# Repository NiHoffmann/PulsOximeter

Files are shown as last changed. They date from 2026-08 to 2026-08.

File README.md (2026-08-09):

# PulsOximeter

> **Group course project.** This was developed as part of a university course together with a project partner. I was responsible for the majority of the **hardware design**, and did **100% of the firmware and filter/signal processing**. My project partner contributed smaller parts of the hardware design (given that he was new to hardware design) and developed the **Android app**.

## Overview
This project implements a complete pulse oximeter system, combining:
- Custom hardware design  
- Embedded firmware development  
- Signal processing (filtering and peak detection)  
- A simple Android app connected via Bluetooth Low Energy (BLE)  

The system measures pulse and oxygen saturation and displays the results in real time on a mobile device.

---

## Hardware
Custom-designed and built PCB with integrated pulse/oximeter sensor.

<p align="center">
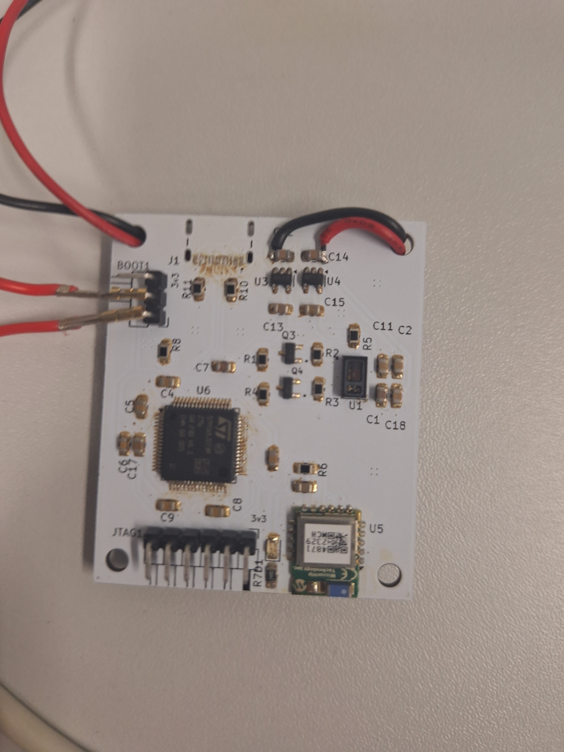
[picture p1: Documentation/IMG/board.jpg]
Hardware Build
  
</p>

---

## Signal Processing
The main emphasis of this project is robust pulse detection from noisy sensor data.
- Bandpass filter designed for 0.8 – 3.5 Hz  
- Covers typical human heart rate range (1.0 – 3.3 Hz) with margin  
- Reduces noise and motion artifacts  
- Enables reliable peak detection for pulse extraction  

Filtered and processed signal:

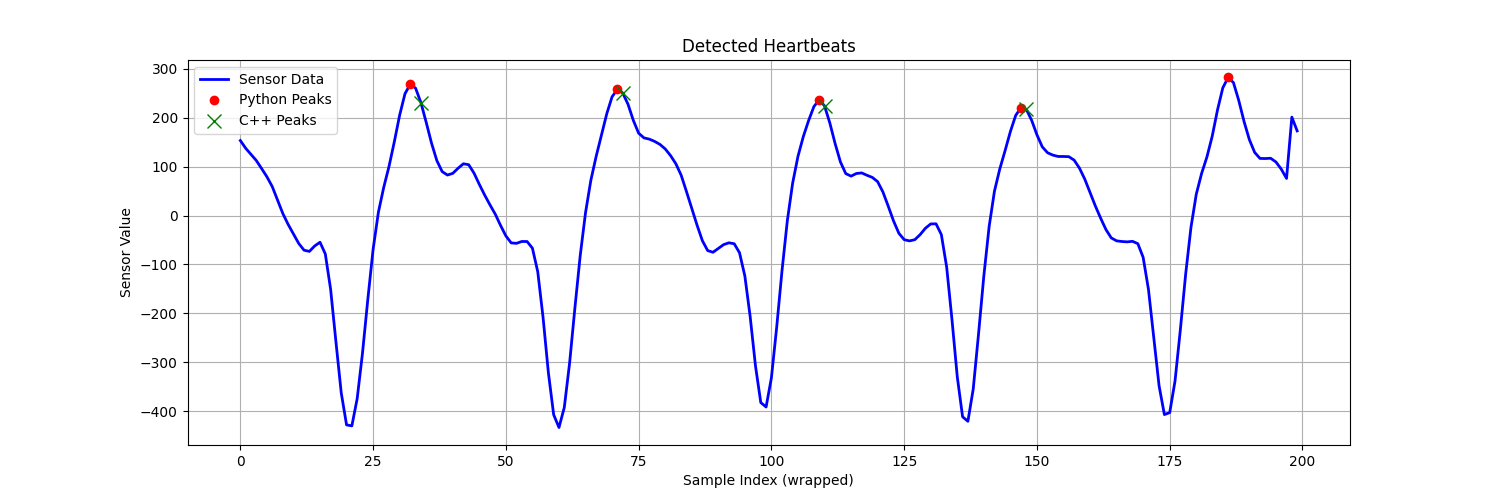
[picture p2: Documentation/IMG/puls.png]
Processed Pulse Signal


> **Filter robustness:** the bandpass filter reliably extracts the pulse waveform whether the raw sensor input is already clean or heavily corrupted by noise.
>
> | Clean Input | High-Noise Input |
> |:---:|:---:|
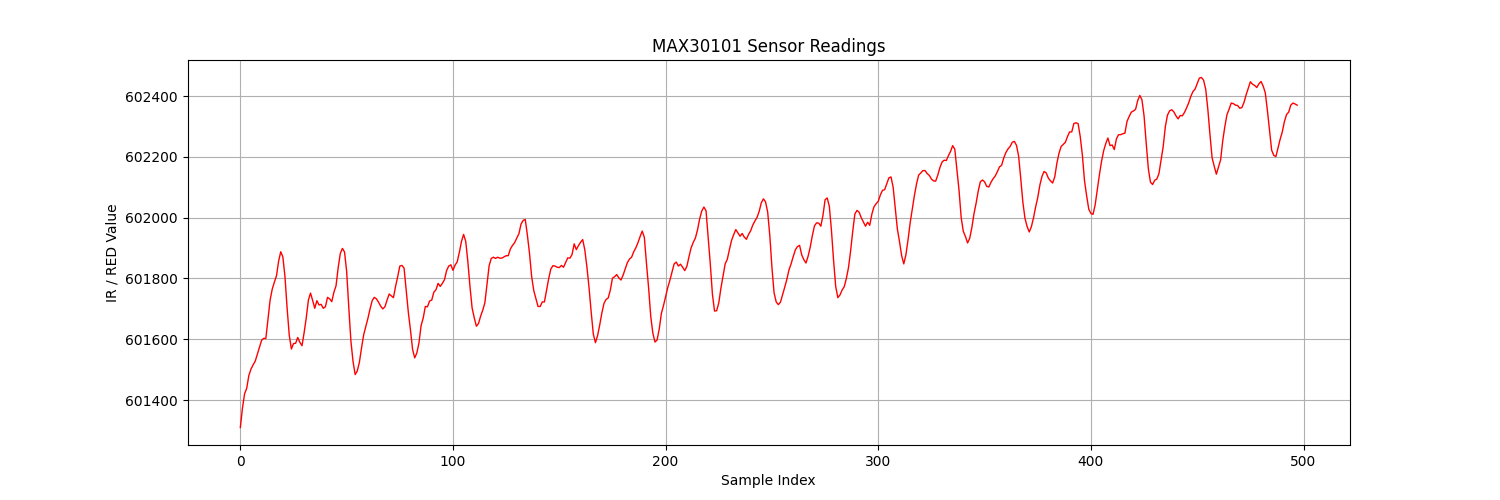
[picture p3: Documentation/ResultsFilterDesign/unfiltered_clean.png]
Filtered result from clean input
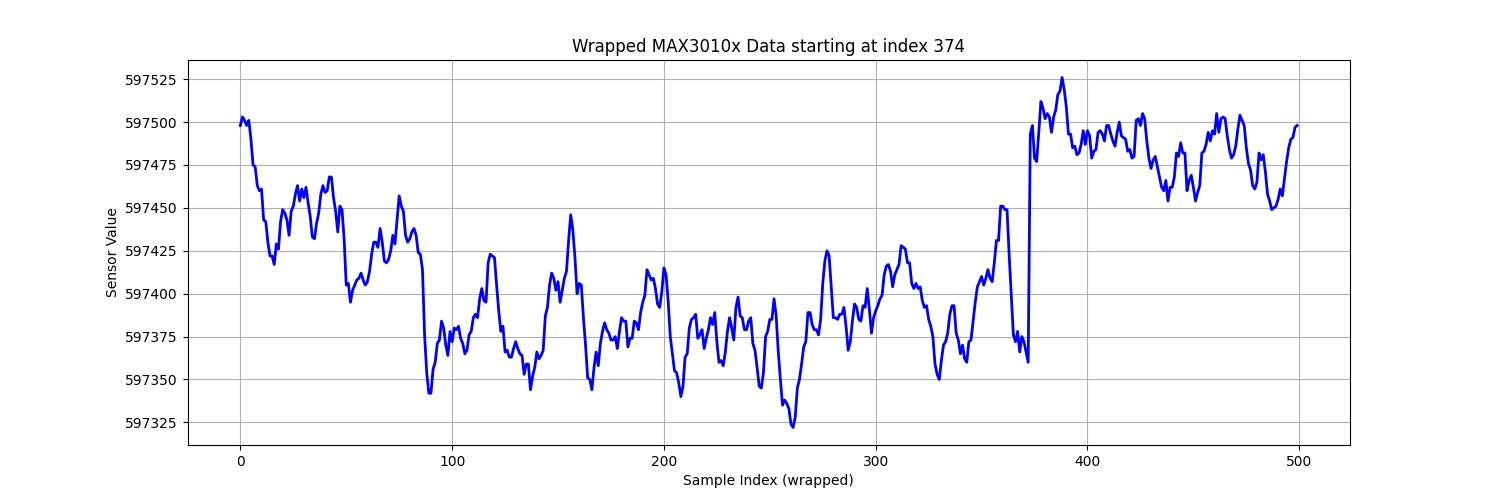
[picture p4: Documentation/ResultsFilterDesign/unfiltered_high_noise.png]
Filtered result from high-noise input
> |  |  |
>
> At first, only a highpass filter was applied to compensate for low-frequency drift. After further testing with higher-noise readings, this was extended to the full bandpass approach shown above.
>
> Note: these plots are sampled from a ring buffer with a non-compensated offset, so the high-noise(~ index 380) and filtered image (~ index 190) show a visible cut/discontinuity where the last reading wraps around to the first.

---

## System Demonstration

### Pulse Measurement on Hardware
Shows real-time pulse detection directly from the device. Recording of messurment run as displayed in "Signal Processing".

[Watch the demo](./Documentation/IMG/Demo_PulseSensorApp.mp4)

---

### App Visualization
Android app displaying measured pulse and oxygen saturation via BLE.

<p align="center">
App Visualization Demo
</p>

---
## Summary
This project demonstrates a complete embedded system with a strong focus on signal processing. The combination of tailored filtering and peak detection enables accurate pulse measurement from noisy sensor data, integrated into a fully functional hardware and software solution.

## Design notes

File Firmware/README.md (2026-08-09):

# Ergebnisse

## Funktionalität des Heart Beat Sensors
- Die Hardware des Heart Beat Sensors ist funktionsfähig.
- Alle gesetzten Ziele wurden erreicht.

## Verbesserungspotential
- Der USB-Port konnte nicht angebracht werden, daher wurde vollständig auf BLE (Bluetooth Low Energy) ausgewichen.
- Der Heart Beat Filter arbeitet zuverlässig, jedoch ist die Peak Detection noch nicht optimal.
- Die CO₂-Berechnung ist technisch korrekt implementiert, jedoch noch nicht kalibriert (siehe Kommentar im Quellcode).

## Anmerkungen zur Datenauswertung
- Im Standardfall würden die Rohdaten an eine App übertragen und dort ausgewertet. Dies ermöglicht eine genauere Berechnung der Peaks (z. B. mittels Python-Skript), die zwar rechenintensiv ist, aber sehr präzise Ergebnisse liefert.
- Für eine Produktionslösung könnte das Erfassen und Filtern der Daten auf dem Gerät erfolgen, während die finale Auswertung in der App stattfindet. Für dieses Embedded-Projekt wurde jedoch der Fokus auf die direkte Ausgabe auf dem Gerät gelegt.

## Disclaimer - Umsetzung und AI-unterstützte Komponenten
Alle Ideen, theoretischen Überlegungen und technischen Umsetzungen wurden eigenhändig durchgeführt, mit Ausnahme der folgenden Komponenten, bei denen AI-Tools zur Erstellung des Grundgerüsts genutzt wurden. Sämtliche Erweiterungen, Anpassungen und Implementierungen darüber hinaus erfolgten manuell:  

- **PeakFinder:** Refactoring von C++ `vector`-basierter Implementierung zu einer statischen Library.  
- **Plot_IR.py:** AI-generiertes Grundgerüst zur Datenvisualisierung; alle weiteren Funktionen und Anpassungen eigenhändig implementiert.  
- **BLE-test.py:** AI-generiertes Grundgerüst für den Datenaustausch; alle weiteren Funktionen und Anpassungen eigenhändig implementiert.  
- **Debugging:** Unterstützung bei der Fehlersuche und Behebung von Problemen.
- **Überarbeitung von Texten:** Formulierung, Rechtschreibung und Grammatik.

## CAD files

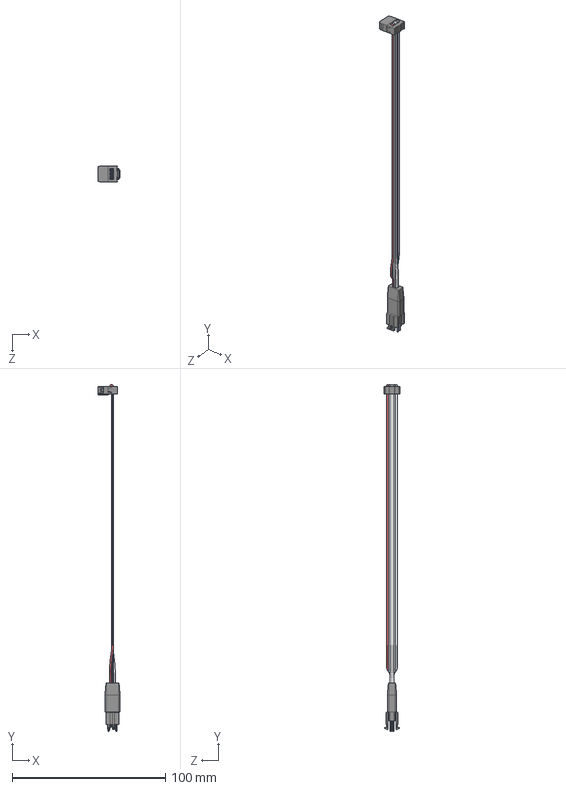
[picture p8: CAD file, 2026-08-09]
Schematics/KiCadSym/8.06.16_J-LINK_6-PIN_NEEDLE_ADAPTER/8.06.16_J-LINK_6-PIN_NEEDLE_ADAPTER.step
14.5 x 226.1 x 10.7 mm

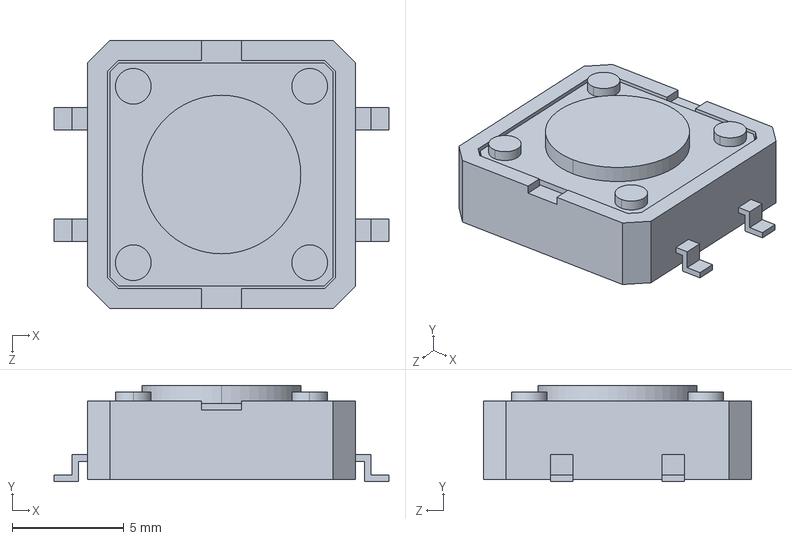
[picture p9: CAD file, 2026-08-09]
Schematics/KiCadSym/B3FS-4002P/B3FS-4002P.step
15.0 x 4.30 x 12.0 mm

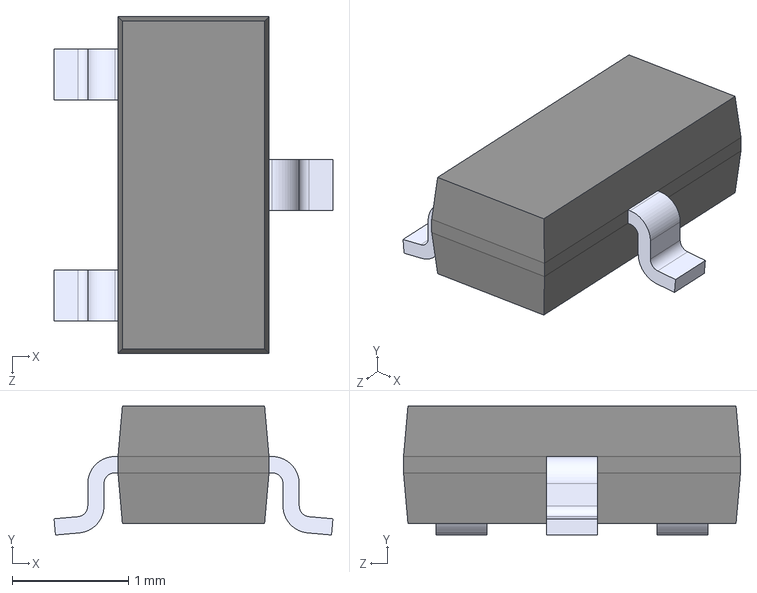
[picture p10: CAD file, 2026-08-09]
Schematics/KiCadSym/BSS138LT3G/BSS138LT3G.step
2.40 x 1.11 x 2.90 mm

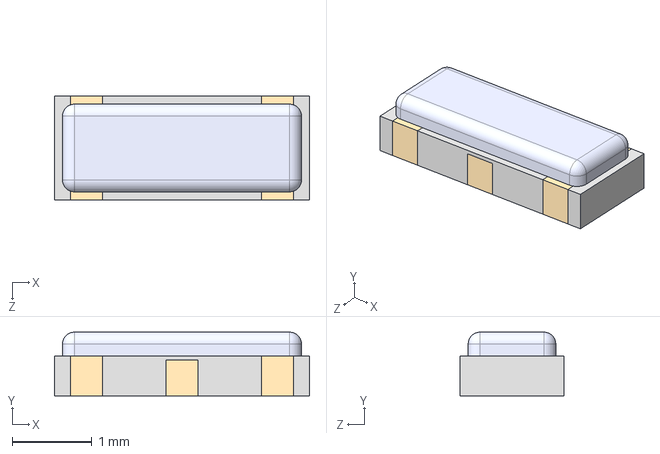
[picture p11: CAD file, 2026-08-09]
Schematics/KiCadSym/CSTNE12M0G520000R0/CSTNE12M0G520000R0.step
3.20 x 0.8 x 1.30 mm

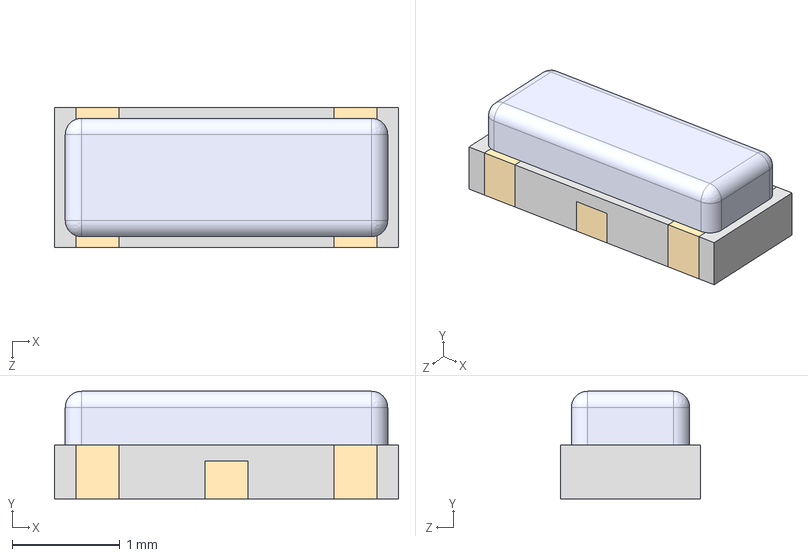
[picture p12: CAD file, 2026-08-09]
Schematics/KiCadSym/CSTNE16M0V53L000R0/CSTNE16M0V53L000R0.step
3.20 x 1.00 x 1.30 mm

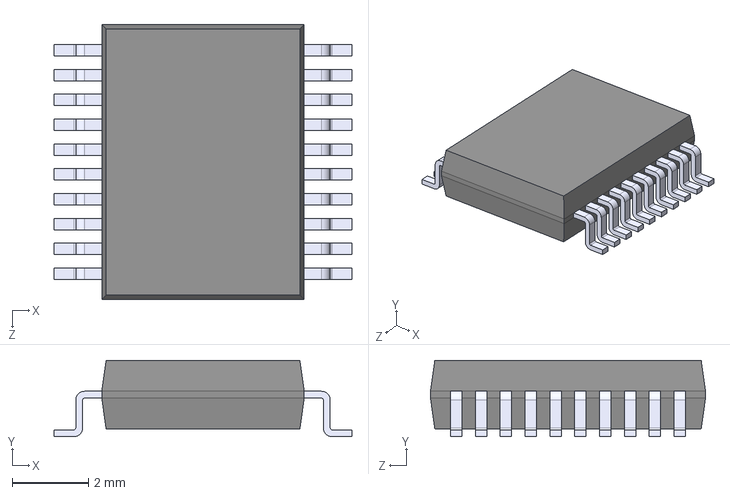
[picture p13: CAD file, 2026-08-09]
Schematics/KiCadSym/MCP2200-I_SS/MCP2200-I_SS.step
7.80 x 2.00 x 7.20 mm

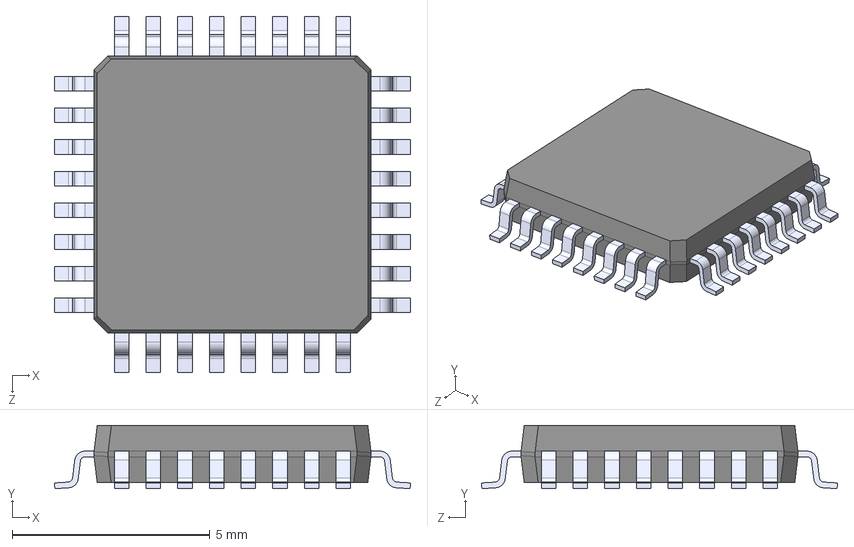
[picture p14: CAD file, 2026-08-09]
Schematics/KiCadSym/QFP80P900X900X160-32N/QFP80P900X900X160-32N.step
9.00 x 1.60 x 9.00 mm

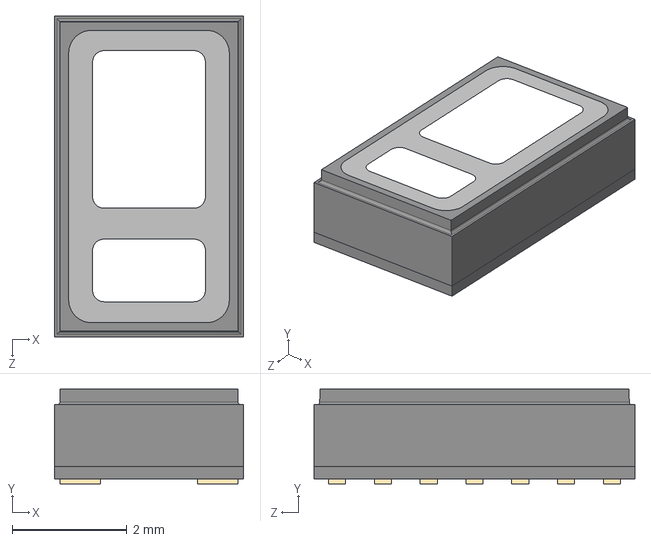
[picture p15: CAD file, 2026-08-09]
Schematics/KiCadSym/MAX30101EFD_T/MAX30101EFD_T.step
3.30 x 1.65 x 5.60 mm

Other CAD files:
Schematics/KiCadSym/STM32L051C8T6/STM32L051C8T6.step
Schematics/KiCadSym/STM32L052C6T6/STM32L052C6T6.step

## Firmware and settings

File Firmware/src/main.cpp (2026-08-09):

#include "Devices/BLE.h"
#include "Devices/HeartBeat.h"
#include <Arduino.h>

#define BLE_INTERVAL 1000

unsigned long last_ble_time = 0;
unsigned long last_sample_time = 0;

#define MOVING_AVERAGE_SCALE 0.3f

char payload[MAX_PAYLOAD_SIZE];

void ble_routine() {
  static float co2_mov_avg = 0;
  static bool first_run = true;

  if (!rn487xBle.getConnectionStatus()) {
    return;
  }

  uint32_t bpm_raw = get_heart_beat();
  uint32_t co2_raw = get_o2();

  uint8_t bpm_capped = (bpm_raw > 255) ? 255 : (uint8_t)bpm_raw;
  uint8_t co2_capped = (co2_raw > 255) ? 255 : (uint8_t)co2_raw;

  if (first_run) {
    co2_mov_avg = co2_capped;
    first_run = false;
  } else {
    co2_mov_avg = MOVING_AVERAGE_SCALE * co2_capped +
                  (1 - MOVING_AVERAGE_SCALE) * co2_mov_avg;
  }

  // round up
  uint8_t co2 = (uint8_t)(co2_mov_avg + 0.5f);

  snprintf(payload, MAX_PAYLOAD_SIZE, "%02X%02X\0", bpm_capped, co2);
  transfer_data(payload);
}

void setup() {
  init_heart_beat_sensor();
  init_ble();
}

void loop() {
  unsigned long current_millis = millis();

  if (current_millis - last_sample_time >= SAMPLING_PERIOD) {
    sample();
    last_sample_time += SAMPLING_PERIOD;
  }

  if (current_millis - last_ble_time >= BLE_INTERVAL) {
    ble_routine();
    last_ble_time += BLE_INTERVAL;
  }
}

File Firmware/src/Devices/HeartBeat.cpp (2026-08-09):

#include "HeartBeat.h"
#include <DataProcessing/Filter.h>
#include <DataProcessing/PeakFinder.h>
#include <Wire.h>
#include <math.h>

MAX30101 heart_beat_sensor = MAX30101(0x57, Wire);

// Sample ring buffer
float red_filtered[SAMPLE_BUFFER];
float ir_filtered[SAMPLE_BUFFER];

int sample_index = 0;
int samples_filled = 0;

IIRFilter hp_filter_red, lp_filter_red;
IIRFilter hp_filter_ir, lp_filter_ir;

void init_heart_beat_sensor() {
  Wire.setSCL(PB6);
  Wire.setSDA(PB7);
  Wire.setClock(100000);

  Wire.begin();

  while (!heart_beat_sensor.begin())
    delay(100);

  // Heart beat is 1 - 3.3 Hz
  init_highpass(&hp_filter_red, 0.8, SAMPLING_FREQUENCY);
  init_lowpass(&lp_filter_red, 3.5, SAMPLING_FREQUENCY);
  init_highpass(&hp_filter_ir, 0.8, SAMPLING_FREQUENCY);
  init_lowpass(&lp_filter_ir, 3.5, SAMPLING_FREQUENCY);
}

void sample() {
  static bool once = true;

  // 200 samples to get the filter going
  if (once) {
    for (int i = 0; i < SAMPLE_BUFFER; i++) {
      MAX30101Sample sample = heart_beat_sensor.readSample();

      // Store in circular buffer
      red_filtered[sample_index] =
          filter_bandpass(&hp_filter_red, &lp_filter_red, sample.red);
      ir_filtered[sample_index] =
          filter_bandpass(&hp_filter_ir, &lp_filter_ir, sample.ir);
      sample_index = (sample_index + 1) % SAMPLE_BUFFER;

      if (samples_filled < SAMPLE_BUFFER) {
        samples_filled++;
      }
      delay(SAMPLING_PERIOD);
    }
    once = false;
  }

  MAX30101Sample sample = heart_beat_sensor.readSample();

  red_filtered[sample_index] =
      filter_bandpass(&hp_filter_red, &lp_filter_red, sample.red);
  ir_filtered[sample_index] =
      filter_bandpass(&hp_filter_ir, &lp_filter_ir, sample.ir);
  sample_index = (sample_index + 1) % SAMPLE_BUFFER;

  if (samples_filled < SAMPLE_BUFFER) {
    samples_filled++;
  }
}

/**
 *
 * Heart beat.
 *
 */

uint32_t get_heart_beat() {
  static float ordered[SAMPLE_BUFFER];
  static int peak_indices[SAMPLE_BUFFER / 2];

  if (samples_filled < SAMPLE_BUFFER)
    return 0;

  memset(ordered, 0, sizeof(ordered));
  memset(peak_indices, 0, sizeof(peak_indices));

  int start = (sample_index + 1) % SAMPLE_BUFFER;
  for (int i = 0; i < SAMPLE_BUFFER; i++) {
    int idx = (start + i) % SAMPLE_BUFFER;
    ordered[i] = (float)red_filtered[idx];
  }

  size_t num_peaks = 0;
  PeakFinder::findPeaks(ordered, SAMPLE_BUFFER, peak_indices, num_peaks, true,
                        1.0f);

  if (num_peaks < 3)
    return 0;

  size_t filtered_count = 0;
  int last_kept = peak_indices[1];
  peak_indices[filtered_count++] = last_kept;

  for (size_t i = 2; i < num_peaks; i++) {
    int dist = peak_indices[i] - last_kept;
    if (dist >= MIN_DISTANCE) {
      last_kept = peak_indices[i];
      peak_indices[filtered_count++] = last_kept;
    }
  }

#if DEBUG_PEAKS
  for (size_t i = filtered_count; i < num_peaks; i++) {
    peak_indices[i] = 0;
  }
#endif

  if (filtered_count < 2)
    return 0;

  float avg_interval_samples = 0.0f;
  for (size_t i = 1; i < filtered_count; i++) {
    avg_interval_samples += (float)(peak_indices[i] - peak_indices[i - 1]);
  }
  avg_interval_samples /= (filtered_count - 1);

  float avg_interval_sec = avg_interval_samples * (SAMPLING_PERIOD / 1000.0f);

  uint32_t bpm = (uint32_t)(60.0f / avg_interval_sec);

  if (bpm < 60 || bpm > 150)
    return 0;

  return bpm;
}

/**
 *
 * SpO2.
 *
 * Formula:
 *
 * ratio = (AC_RED / DC_RED) / (AC_IR / DC_IR)
 * SpO2 = Basevalue - ratio * callibration_contant
 *
 * see:
 * https://forum.arduino.cc/t/afe4403-spo2-calculation/458889
 *
 * We use calculations and callibrations as described here:
 * https://www.analog.com/en/resources/technical-articles/guidelines-for-spo2-measurement--maxim-integrated.html
 *
 */

float dc_part(float *samples) {
  float sum = 0.0f;
  for (int i = 0; i < SAMPLE_BUFFER; i++) {
    sum += samples[i];
  }
  return sum / SAMPLE_BUFFER;
}

// RMS
float ac_part(float *samples) {
  float dc = dc_part(samples);
  double ac_sum = 0.0f;
  float x = 0;
  for (int i = 0; i < SAMPLE_BUFFER; i++) {
    x = samples[i] - dc;
    ac_sum += x * x;
  }
  return sqrt(ac_sum / SAMPLE_BUFFER);
}

float calculate_ratio_of_ratios() {
  float ac_red = ac_part(red_filtered);
  float dc_red = dc_part(red_filtered);

  float ac_ir = ac_part(ir_filtered);
  float dc_ir = dc_part(ir_filtered);

  if (dc_red == 0 || dc_ir == 0)
    return 0.0f;

  float ratio = (ac_red / dc_red) / (ac_ir / dc_ir);
  return ratio;
}

/**
 *
 *
 * Producer provided callibrations.
 *
 */
const float a = 1.5958422;
const float b = -34.6596622;
const float c = 112.6898759;
float ratio_to_spo2(float ratio) {
  float spo2 = (a * ratio * ratio) + (b * ratio) + c;

  if (spo2 > 100.0f)
    spo2 = 100.0f;
  if (spo2 < 0.0f)
    spo2 = 0.0f;

  return spo2;
}

uint32_t get_o2() {
  float ratio = calculate_ratio_of_ratios();
  return ratio_to_spo2(ratio);
}
